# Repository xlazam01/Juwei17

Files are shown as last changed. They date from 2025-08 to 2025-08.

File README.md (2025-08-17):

<div align="center">
  <h1>Juwei17 Mount Upgrade</h1>
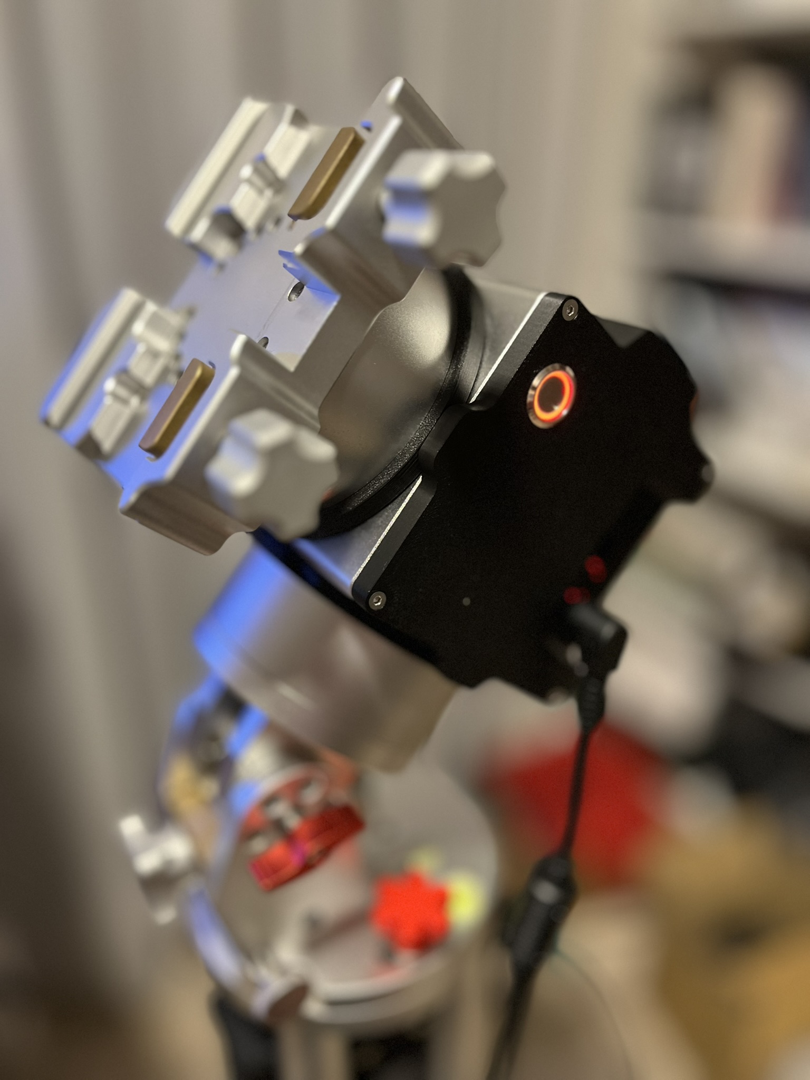
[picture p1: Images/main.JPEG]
  
</div>

## 🚀 Project Overview

This repository contains subprojects to upgrade the Juwei17 mount with enhanced hardware, software, and mechanics. The goal is to provide a modern, feature-rich, and user-friendly experience for astronomy enthusiasts.

---

## 🧑‍🔧 Skills Needed

 - Project is very DIY oriented
 - PCB is very dense and it is recommended to manufacture it via some service (JLCPCB or similar)
 - Some soldering (hall sensors, BME280, switch, connector crimping)

---

## ✨ Upgrade Features

- **Larger on/off switch**
- **Homing**
- **GPS**
- **Weather sensors**
- **Fast slewing possible**
- **Support for TMC SPI or UART modules**  
  (TMC2209, TMC2130, TMC5160, etc.)
- **USB-C connector**
- **Programming button** (no ST-Link needed)
- **Loader application** (semi-automatic programming for OnStep and SWS)

---

## 🧩 Hardware Features

- Minimized PCB size
- Support for Home and Limit switches
- OnWire interface
- GPS interface
- STM32F446 as main processor
- Power switch not needed:
  - Mount will start without switch connected
  - No high current goes through switch itself
  - When switch is closed, mount is off

---

## 💾 Software Features

- Based on OnStepX (preconfigured, just upload)
- Added STM32 RTC support
- Modified Weather:
  - Due to excessive BME self-heating
  - Temperature from DS1820
  - Humidity and pressure from BME280
- TLS fallback (STM32 → GPS)
- PlatformIO is used for OnStepX - My preferred IDE
- Arduino for SWS - due to specific version of ESP toolchain needed

---

## 🏗️ Mechanics

- CAD files
- STL files for 3D printing new covers

---

## 📦 Required Components

- New hardware - data on this github repo
- 2x TMC Drivers - you can reuse TMC2209 from your original main board
  - TMC2209 UART - [link](https://www.aliexpress.com/item/33028050145.html)
  - TMC2130 SPI - [link](https://www.aliexpress.com/item/32970150483.html)
  - TMC5160 SPI - [link](https://www.aliexpress.com/item/1005006043696147.html)
- Beitian BK-280 GPS module -  [link](https://www.aliexpress.com/item/1005009032383874.html)
- BME280 module - [link](https://www.aliexpress.com/item/1005007070789246.html)
- DS1820 - [link](https://www.aliexpress.com/item/1005009032259334.html)
- 2× 3144 hall sensors for homing functionality [link](https://www.aliexpress.com/item/1005008305500149.html)
- 16mm antivandal switch - 16mm, 12-24V, latching - [link](https://www.aliexpress.com/item/1005007144363231.html)
- Wires, connectors, hot glue, etc.
- Crimping pliers (Iwiss IWS-2820M)
- Magnetic rings:
  - Magnets 20×5×2mm [link](https://www.aliexpress.com/item/1005009668801201.html)
    ⚠️ *Warning: Large deviation in sizes experienced!*
- Screws M2×6 Voron style self-tapping screws - [link](https://www.aliexpress.com/item/1005003604942716.html)
- 4x M3x16, 4x  M3x10 countersunk
- optional 3144 hall sensor module for test [link](https://www.aliexpress.com/item/1005009110720818.html)
  - 5V power
  - It can help you to check polarity and sensitivity for you DIY magnet rings

---

## 🛠️ Building Tips

- Use hot glue to fix hall sensors and wires
- Mind the hall sensor "polarity" and magnets orientation in rings - good to check with dry run before mounting everything together

---

## 📁 Folder Description

- **CAD**: SolidEdge models (`*.par` files)
- **HW**: KiCad files (design and schematic PDF)
- **Images**: Build images
- **OnstepEspLoader**: Python app to support you through flashing process
- **OnStepX**: OnStep code (PlatformIO and VSCode)
- **SmartWebServer**: ESP8266 code (built in Arduino due to specific Espressif version)
- **STLs**: Files for 3D printing

---

## 📝 ToDo

- PEC

---

## 🖼️ Photo Gallery
<div align="center">
    Juwei17 Upgrade
</div>

<div align="center">
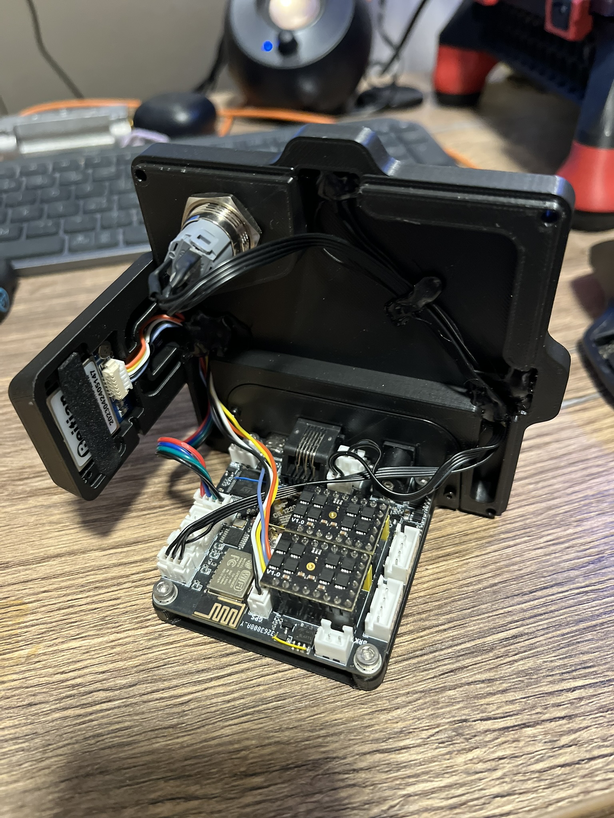
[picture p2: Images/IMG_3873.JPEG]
    
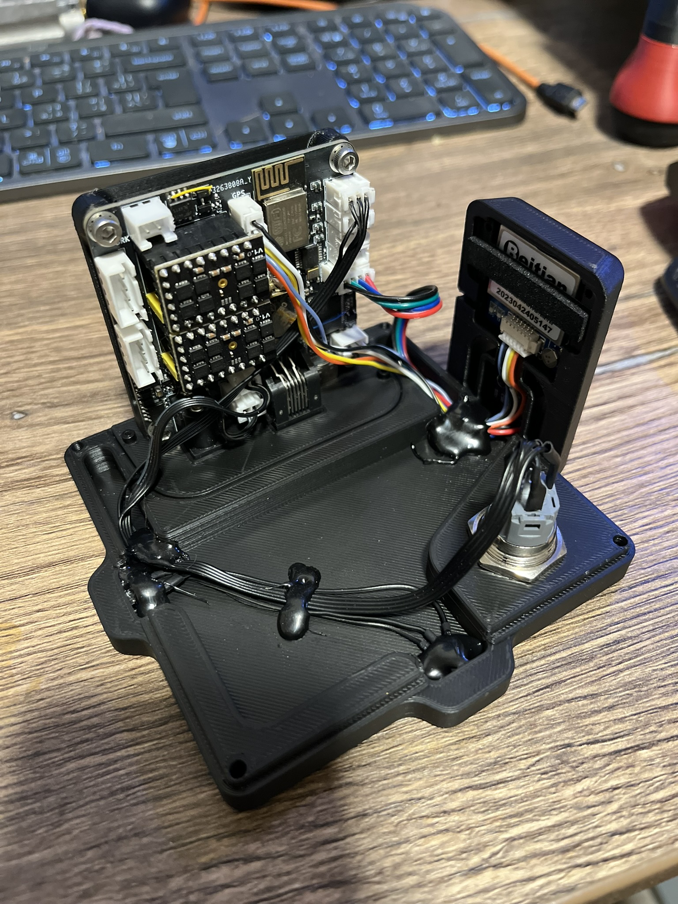
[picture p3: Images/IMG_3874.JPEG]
    
</div>
<div align="center">
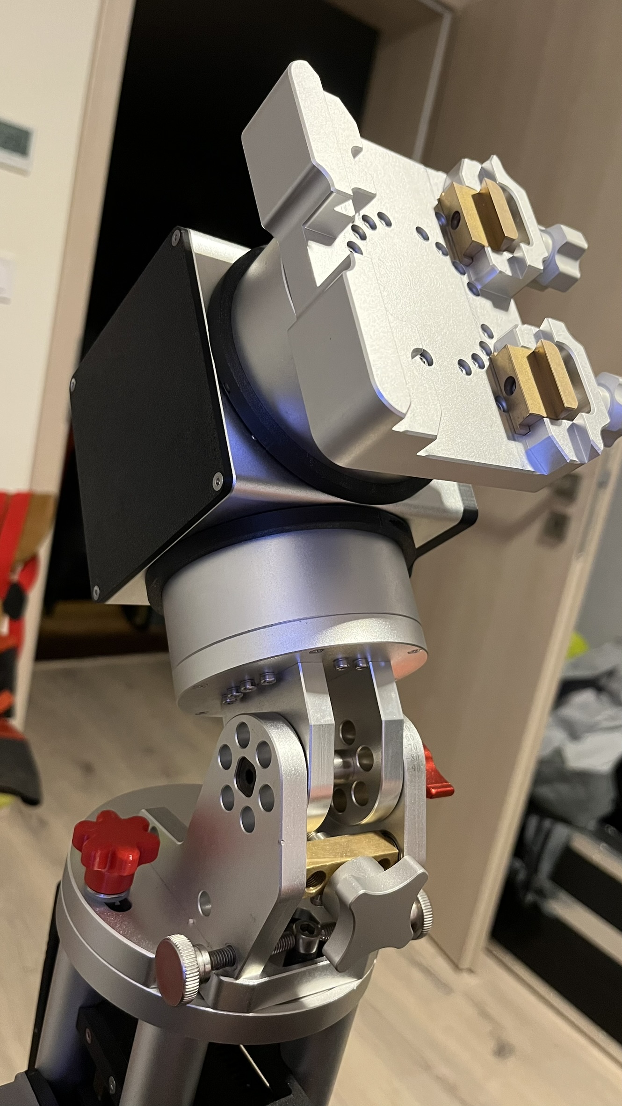
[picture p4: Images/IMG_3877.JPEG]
    
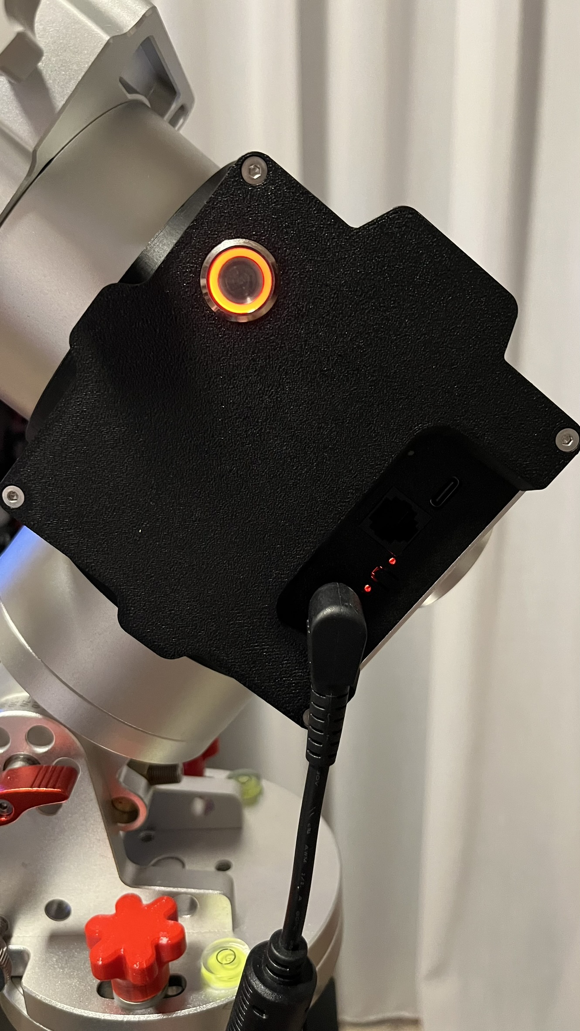
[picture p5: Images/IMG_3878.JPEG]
    
</div>
<div align="center">
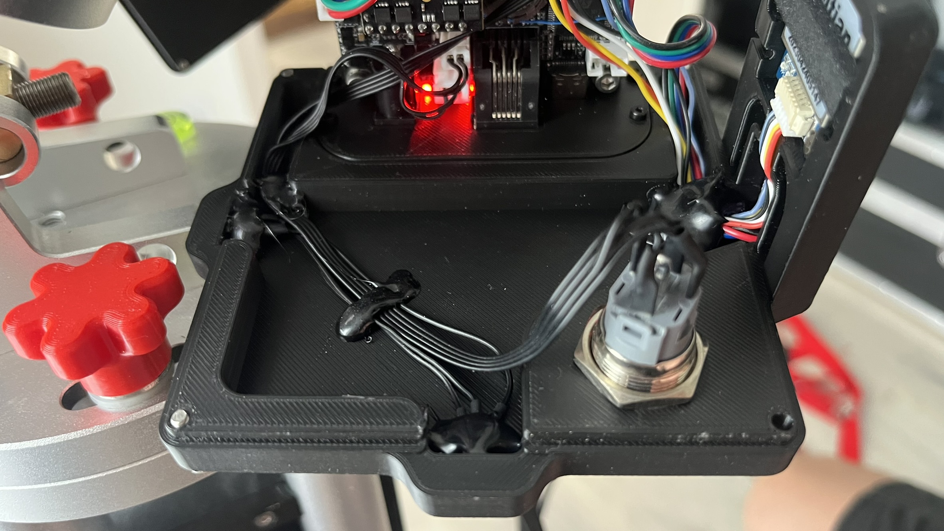
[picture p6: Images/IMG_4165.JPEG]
    
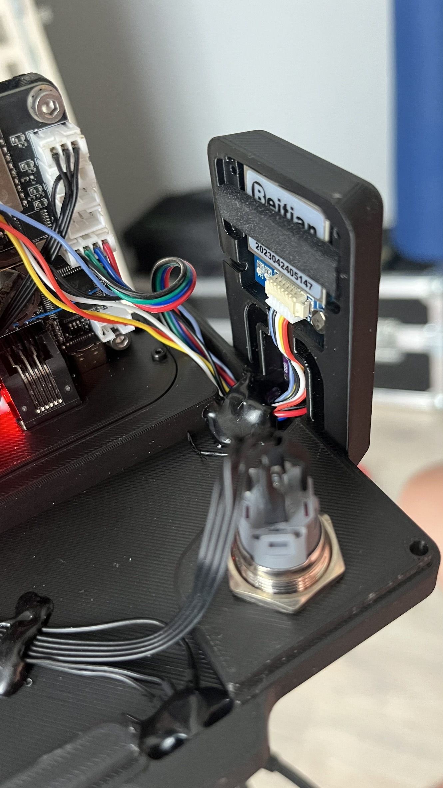
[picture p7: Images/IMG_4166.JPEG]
    
</div>
<div align="center">
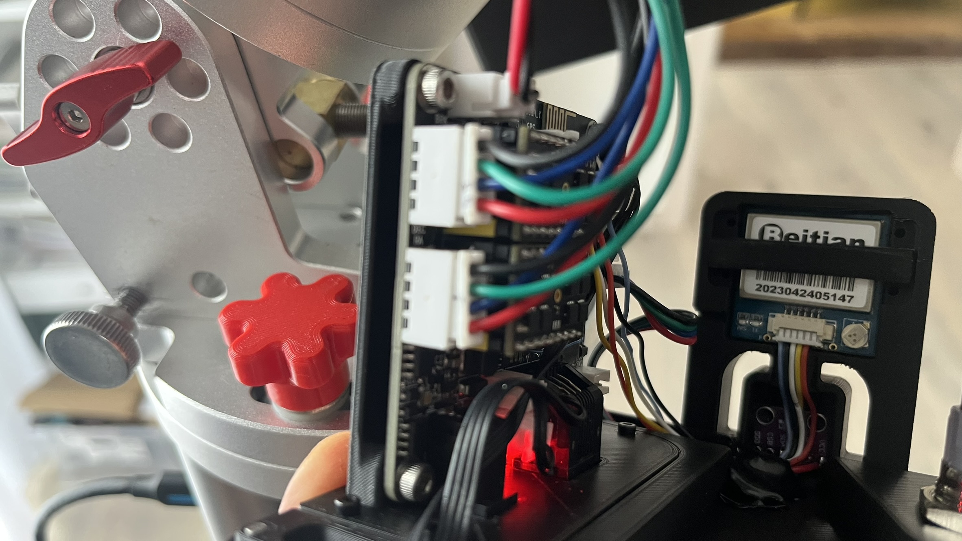
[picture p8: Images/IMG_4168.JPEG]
    
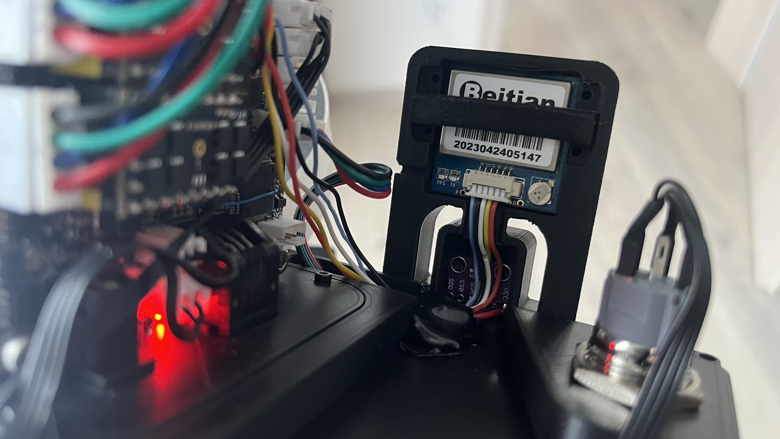
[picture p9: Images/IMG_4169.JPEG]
    
</div>
<div align="center">
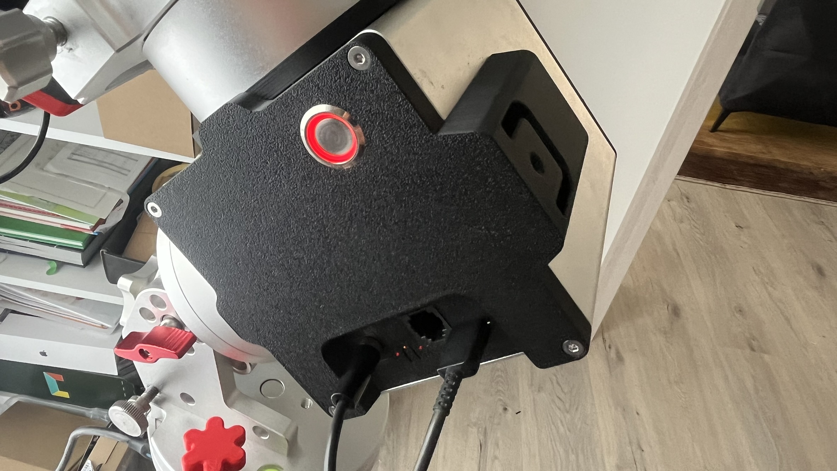
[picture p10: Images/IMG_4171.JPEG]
    
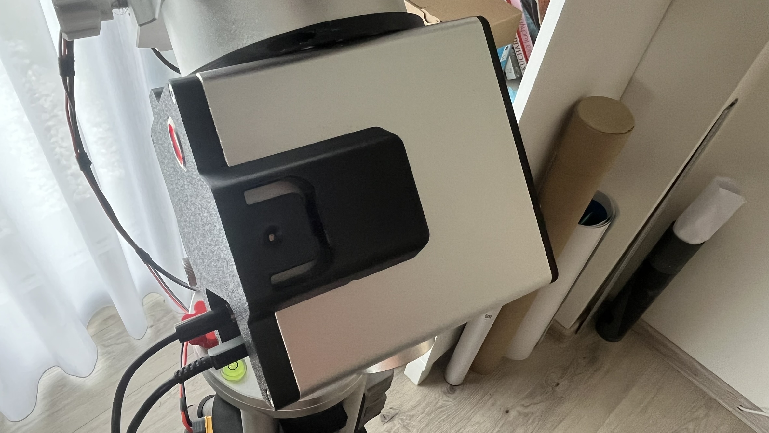
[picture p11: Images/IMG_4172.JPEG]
    
</div>
<div align="center">
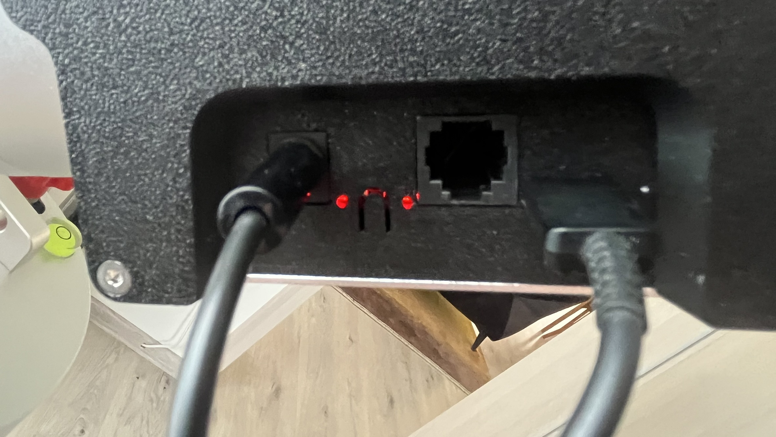
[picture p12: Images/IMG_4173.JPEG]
    
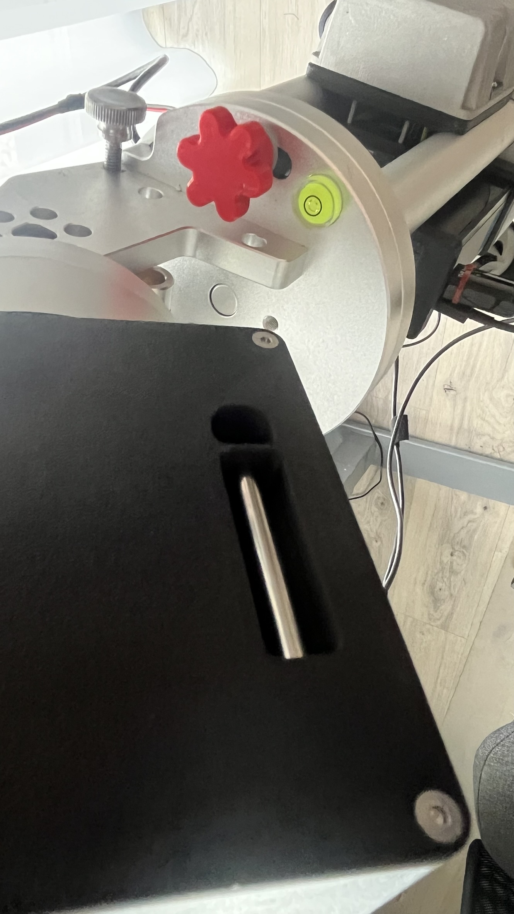
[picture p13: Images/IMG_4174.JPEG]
    
</div>

---

## 🛠️ Assembly Instructions

1. **Print the required parts.**
2. **Prepare magnets for the magnet rings:**
    - Ensure all magnets are oriented in the same direction.
    - Take care to prevent magnets from snapping together unexpectedly.
    - Test magnet polarity using a 3144 module or a bare sensor.
3. **Insert magnets into the rings.**
    - Fill roughly 90-180degrees
4. **Secure magnets with a thin layer of epoxy.**
    - 5min epoxy is ideal
5. **Assemble the front cover using small screws.**
    - Put together PCB_holder and front_panel
6. **Install hall sensors and wiring into the new cover.**
    - Insert hall sensor with right orientation (double check)
    - Fix them in place with hotglue
7. **Mount the new 16mm switch and do wiring.**
    - We use NO contact for mount ON, NC contact for mount OFF
    - Switch backlight is connected to mainboard
8. **Prepare and install wiring for the GPS and BME280 modules.**
    - Solder longer wires and cut them later to perfect length for BME280
    - For GPS just cut the wire to perfect length
    - Install modules in cavities
    - Fix GPS with GPS_holder and small screws
9. **Install the DS1820 sensor in the second cover.**
    - Pressfit the sensor in place
    - Cut wires to size
10. **Secure all wires with hot glue.**
    - Aim is to not have wires getting pinched during cover installation
11. **Trim wires to length and crimp connectors.**
12. **Plug in jumper for UART/SPI TMC**
13. **Insert TMC modules**
14. **PCB installation**
    - Reuse brass standoff - insert them into holes in front cover
    - Attach the PCB to these standoffs    
15. **Connect all components together.**
    - Install back cover
    - Plug in all connectors
    - Install front cover
    - Screw in four screws for the PCB from the bottom of the mount
16. **Assembly complete!**

---

<div align="center">
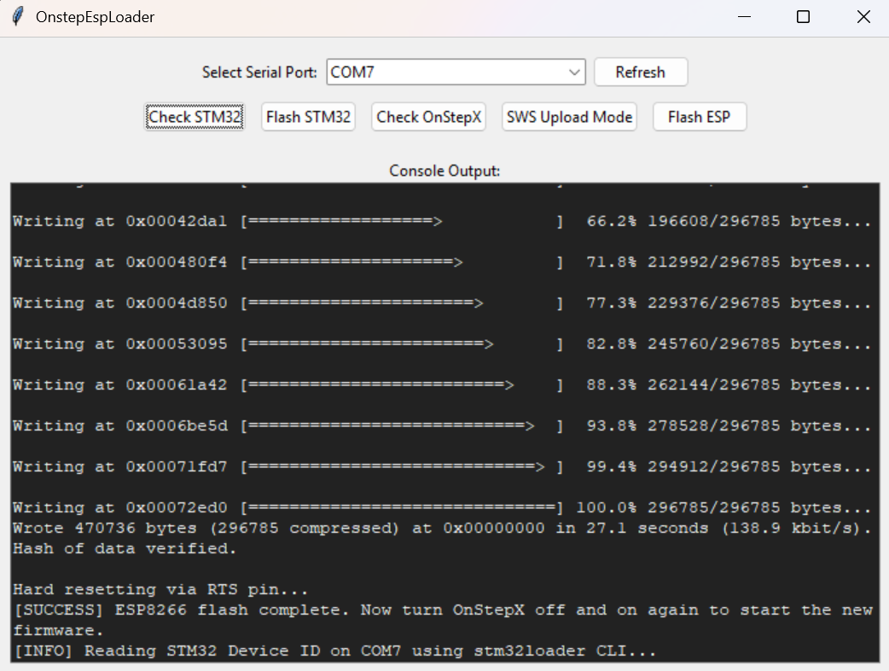
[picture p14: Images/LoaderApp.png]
    
</div>

## 💻 Firmware Upload

1. **Power off the device.**
2. **Press and hold the button** next to the power connector.
3. **Power on the device.**
4. **Observe the LEDs:**
    - OnStep status LED will be off.
    - WiFi LED will blink if firmware is present; if the ESP is empty, both LEDs will be off.
5. **Start the OnstepEspLoader Python app.**
6. **Select the correct TMC module type.**
7. **Choose homing**
8. **Click "Check STM32":**
    - The bootloader should respond.
    - If it fails, click again.
9. **Click "Upload STM32":**
    - Firmware upload will start.
10. **Wait for the OnStep status LED:**
    - It should turn on after some time.
    - The first boot may take longer as EEPROM is being formatted.
11. **Click "Check OnStep":**
    - It should respond with name and version.
12. **Switch to SWS mode:**
    - OnStep enters transparent mode and is ready to upload ESP firmware.
13. **Click "Upload ESP":**
    - Firmware for the webserver will be uploaded to the ESP.
14. **Finish:**
    - A soft reset will occur after some time, or you can power cycle the device manually.

---

## ⚙️ Default Firmware Configuration

Default firmware configuration expects:
- BME280, DS1820 - if initialization fails, there will be no weather information on webserver
- TMC2209, TMC5160 or TMC2130 - according to selected firmware during programming
- Correct polarity of HAL sensors for homing - if not fulfilled, homing will not work correctly
- Motor current is set to 1.0A for RUN and 1.3A for GOTO
- Homing sense is HIGH

---

## 🏗️ Build Your Own OnStepX

- If you use OnStepX from Howard Dutton - there will be no support for STM32 RTC (time and date will not be stored) and weather service will provide false temperatures from BME280 (self-heating)
 - This could be potentially merged into main branch (I know that STM32 RTC was not planned - there are no official boards ready for this, weather fix is open)
- For my Juwei17 board use the OnStepX from this repository
- Change configuration as needed
- For upload use Serial Bootloader - depending on your IDE (Arduino, PlatformIO) how to do it 
- There are three pads on the bottom of the PCB to connect to ST-Link - you need to solder wires or a connector with 2mm pitch
- If you want to use OnstepEspLoader just browse for your STM32 firmware binary
- Binary file pattern:

| Firmware Name | TMC Module | Homing |
|---|---|---|
| firmware_5160_wH | TMC5160 | With Homing |
| firmware_5160_woH | TMC5160 | Without Homing |
| firmware_2130_wH | TMC2130 | With Homing |
| firmware_2130_woH | TMC2130 | Without Homing |
| firmware_2209_wH | TMC2209 | With Homing |
| firmware_2209_woH | TMC2209 | Without Homing |

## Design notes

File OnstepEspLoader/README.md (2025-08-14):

# OnstepEspLoader

This is a Python application designed to upload
- firmware.bin binary file to STM32 over serial bootloader - use #serialScript.py for this
- SmartWebServer.ino.bin binary file to ESP8266

## Features
- Check presence of STM32 bootloader by get part ID
- Flash STM32 in serial bootloader
- Check presence of OnStepX
- Switch STM32 to transparent serial port by sending :hF#:ESPFLASH# to OnStep at 9600 baud to enable SWS upload mode.
- Flash ESP with SmartWebServer

## Requirements
- Python 3.7+
- pip

## Setup
1. Install dependencies:
   ```sh
   pip install stm32loader
   pip install pyserial
   ```
2. Connect your STM32/ESP32 device via USB.
3. Run the application:
   ```sh
   python main.py
   ```

## Usage
- Follow the buttons - they are self explanatory
- The script will handle the upload process.

## License
MIT

---

## 🖼️ Photo Gallery

<div align="center">
  Juwei17 Upgrade
</div>

<div align="center">
  
  
</div>
<div align="center">
  
  
</div>
<div align="center">
  
  
</div>
<div align="center">
  
  
</div>
<div align="center">
  
  
</div>
<div align="center">
  
  
</div>

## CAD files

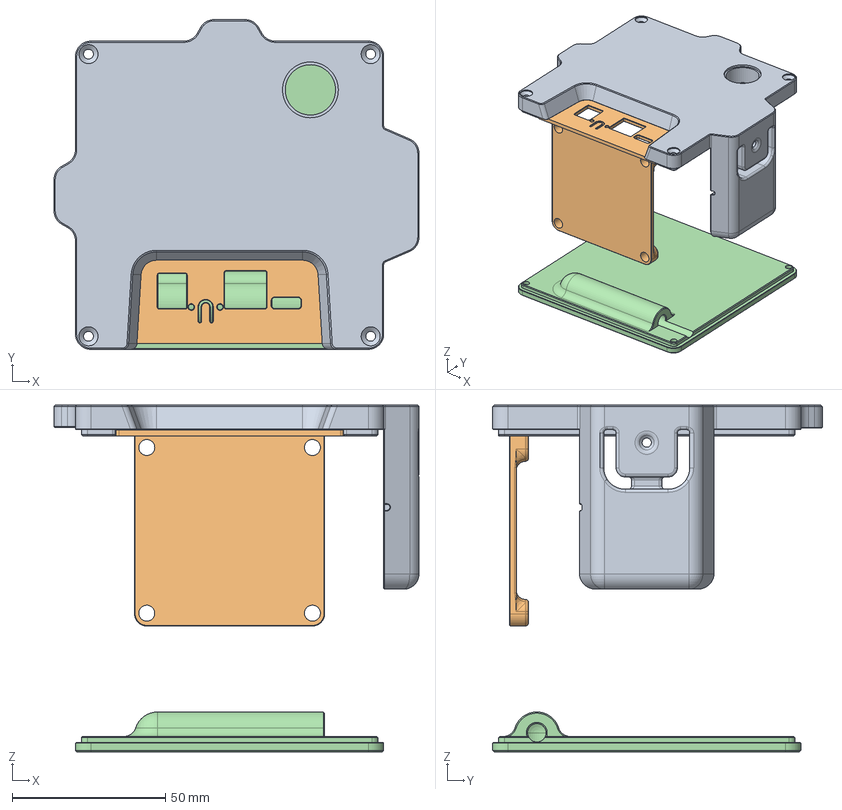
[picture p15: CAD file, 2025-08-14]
CAD/complete_assembly.stp
119.0 x 107.5 x 113.0 mm

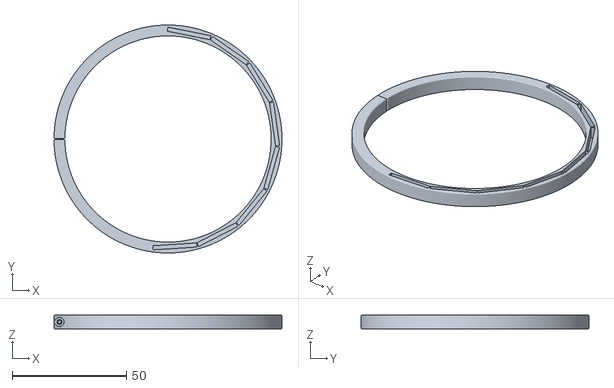
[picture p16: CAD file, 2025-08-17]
STLs/homing_ring.stl
100.0 x 100.0 x 6.00

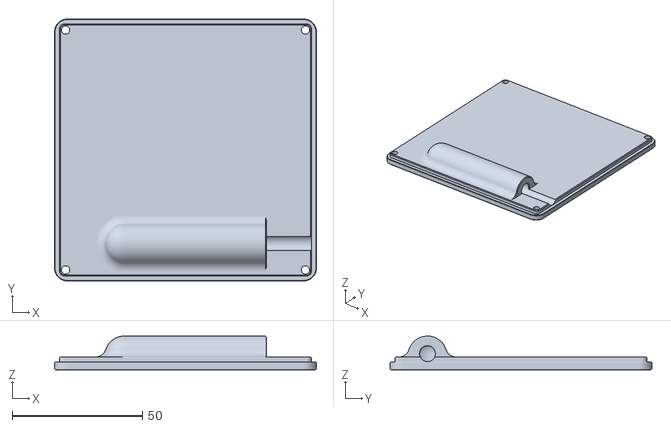
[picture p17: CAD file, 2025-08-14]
STLs/back_cover_DS1820_inside.stl
100.5 x 100.5 x 13.0

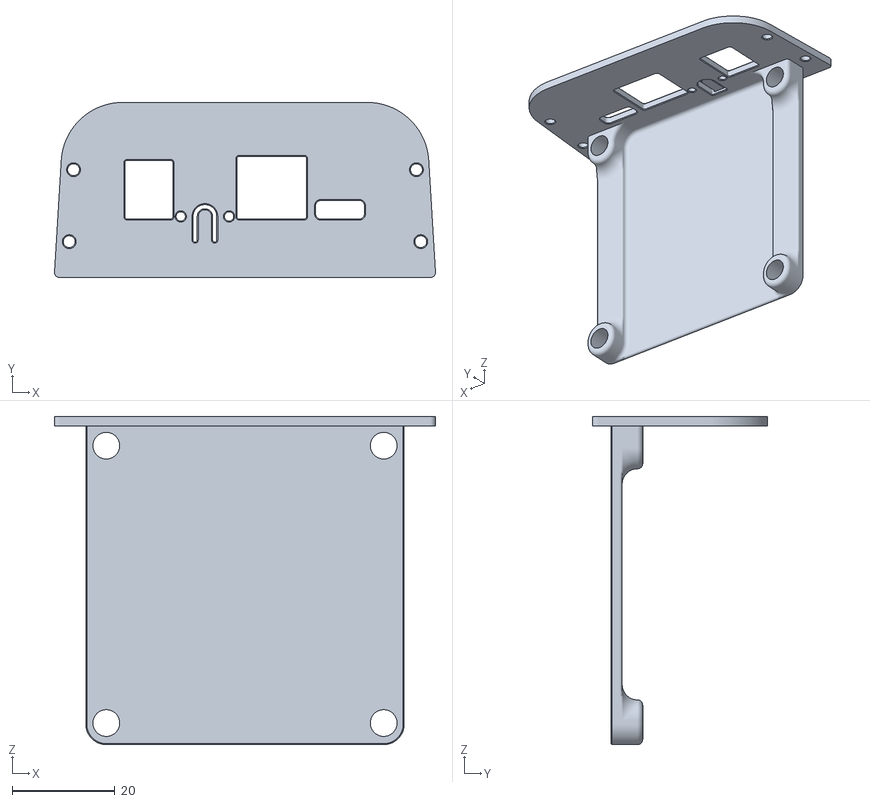
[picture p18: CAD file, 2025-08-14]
STLs/PCB_front_RJsmall.stl
74.2 x 34.1 x 63.9

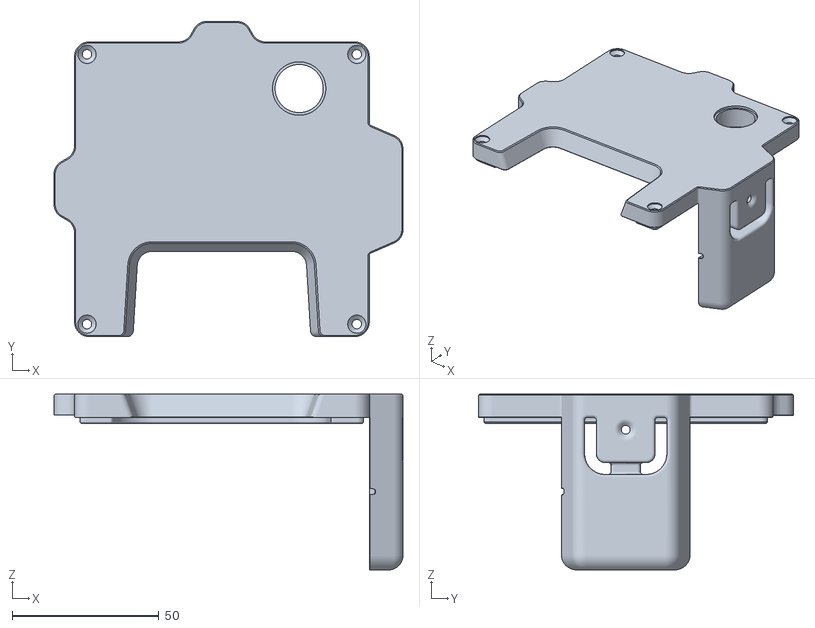
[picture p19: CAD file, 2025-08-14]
STLs/front_cover_16mm_GPS_BME.stl
119.0 x 107.5 x 60.0

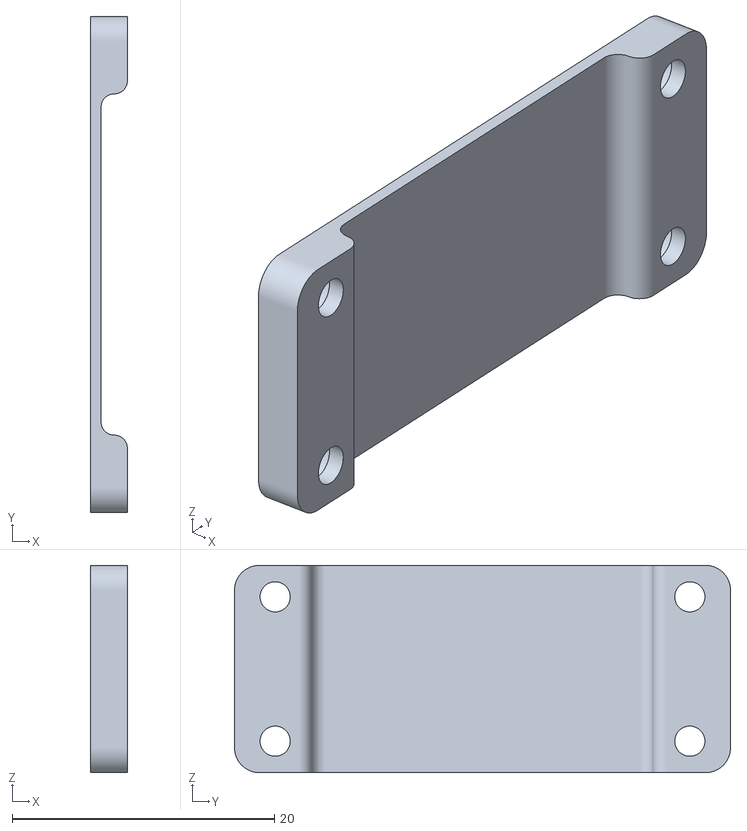
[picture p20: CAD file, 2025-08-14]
STLs/GPS_holder.stl
2.80 x 37.8 x 15.8

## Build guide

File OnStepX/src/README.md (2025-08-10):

OnStepX Telescope Controller
===========================

# What is OnStepX?
OnStepX is the advanced version of the OnStep computerized telescope controller with support for interfacing with/controlling a variety of motor drivers (and so motors) including Step/Dir, ODrive, and Servo (a combination of encoder and DC motor or Stepper motor) types.

It supports:
* Telescope Mount control (Alt/Azm and Equatorial GEM/Fork.)  Optional support for Eq mounts with Tangent Arm Declination.  Usually the Goto capability is enabled, but that's optional as well for those who just want basic mount control.
* Telescope Rotator control (including Alt/Azm de-rotation.)
* Telescope Focuser control (up to 6 focusers so it can handle collimation as well as focusing.)
* Telescope Accessory control (combination of up to 8 dew-heaters, switches, analog PWM.)

# Features
OnStepX supports a wide variety of connection options.  Several serial
"command channels" can be utilized. One of the these is normally devoted to a USB
connection and for the other(s) choose from the following:

* Bluetooth
* ESP8266 WiFi
* Arduino M0/Ethernet Shield
* Even another USB port or RS232 serial isn't very difficult to add.

In the case of running OnStepX on an ESP32 it can provide its own Bluetooth or WiFi IP command channels without additional hardware by simply activating the feature in OnStepX.

Other software in the OnStep ecosystem include:

* an [ASCOM](http://ascom-standards.org/) driver (with IP and Serial support),
* an Android App useable over WiFi or Bluetooth equipped Phones/Tablets,
* a "built-in" website (on the Ethernet and/or WiFi device),
* a full planetarium program that controls all features ([Sky Planetarium](http://stellarjourney.com/index.php?r=site/software_sky)).

OnStep is compatible with the LX200 protocol. This means it can be controlled
from other planetarium software, like: Sky Safari, CdC (even without ASCOM),
Stellarium, etc.

There are also [INDI](http://www.indilib.org/about.html) drivers so it can be used from Linux, with CdC or KStars.

# Documentation
Detailed documentation, including the full set of features, detailed designs for
PCBs, instructions on how to build a controller, how to configure the firmware
for your particular mount, can all be found the [OnStep Group Wiki](https://groups.io/g/onstep/wiki/home).

# Change Log
All the changes are tracking in git, and a detailed list can be accessed using the
following git command:
 
git log --date=short --pretty=format:"%h %ad %<(20)%an %<(150,trunc)%s"

# Support
Questions and discussion should be on the mailing list (also accessible via the
web) at the [OnStep Group](https://groups.io/g/onstep/).

# License
OnStep is open source free software, licensed under the GPL.

See [LICENSE.txt](./LICENSE.txt) file.

# Author
[Howard Dutton](http://www.stellarjourney.com)

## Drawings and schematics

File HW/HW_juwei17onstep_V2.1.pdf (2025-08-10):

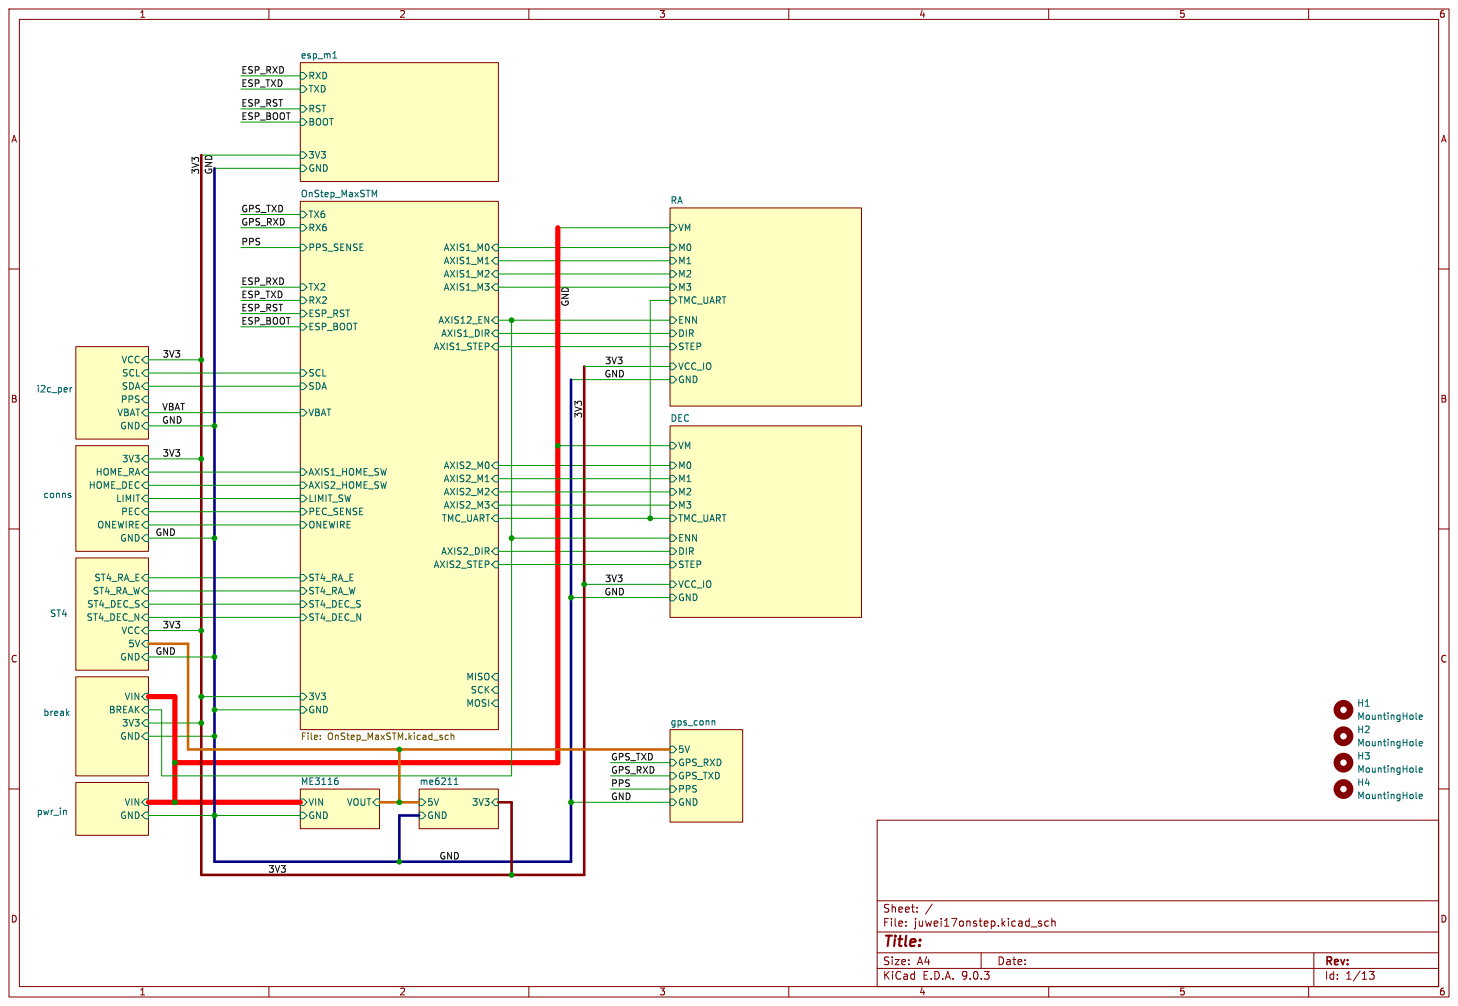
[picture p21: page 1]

Id: 1/13 Title: File: juwei17onstep.kicad_sch Sheet: /

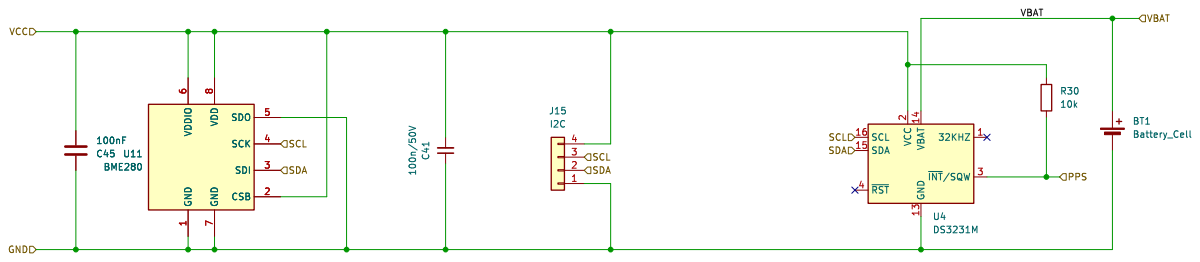
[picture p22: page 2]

7 SDO 5 SCK 4 SDI 3 CSB 2 U11 BME280

7 SDO 5 SCK 4 SDI 3 CSB 2

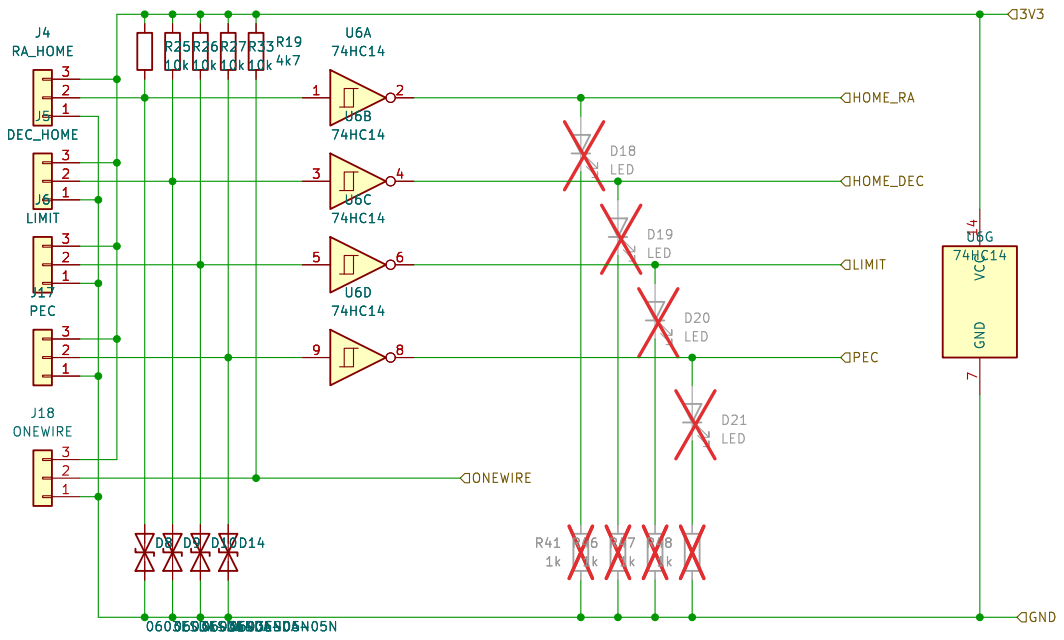
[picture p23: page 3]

Id: 11/13 Title: File: conns.kicad_sch Sheet: /conns/

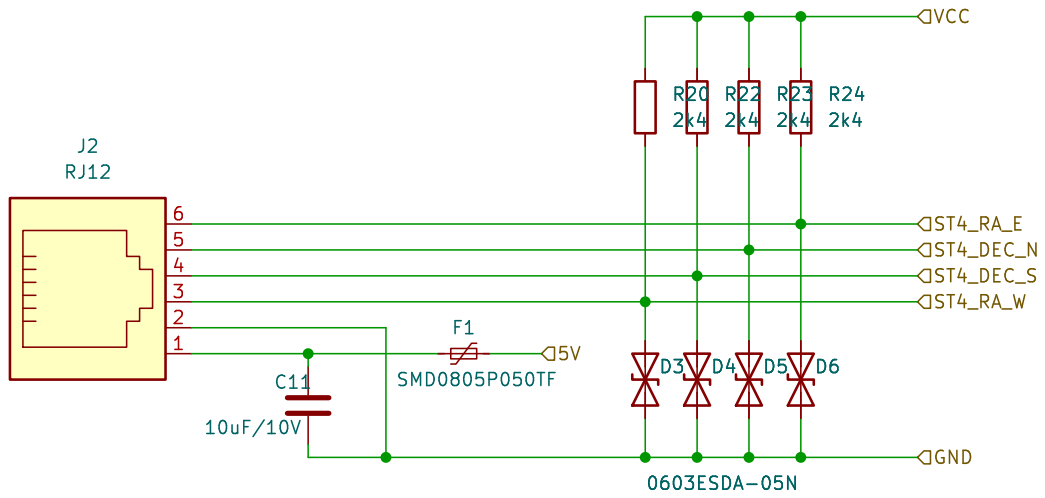
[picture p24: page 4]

Id: 7/13 Title: File: ST4.kicad_sch Sheet: /ST4/

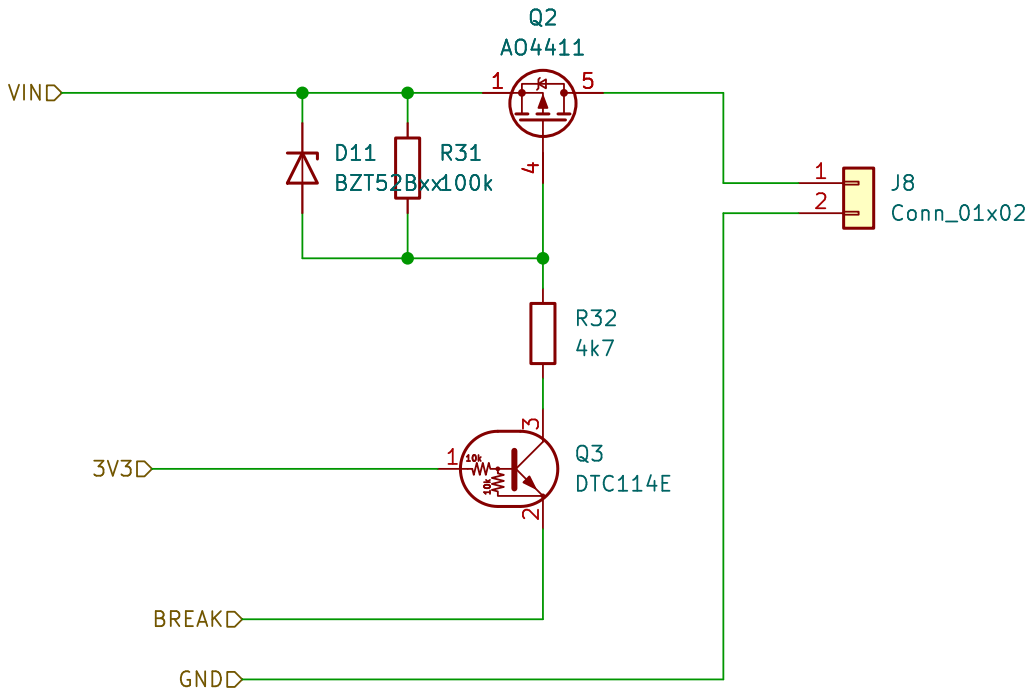
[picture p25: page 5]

Id: 14/13 Title: File: break.kicad_sch Sheet: /break/ D11 BZT52Bxx

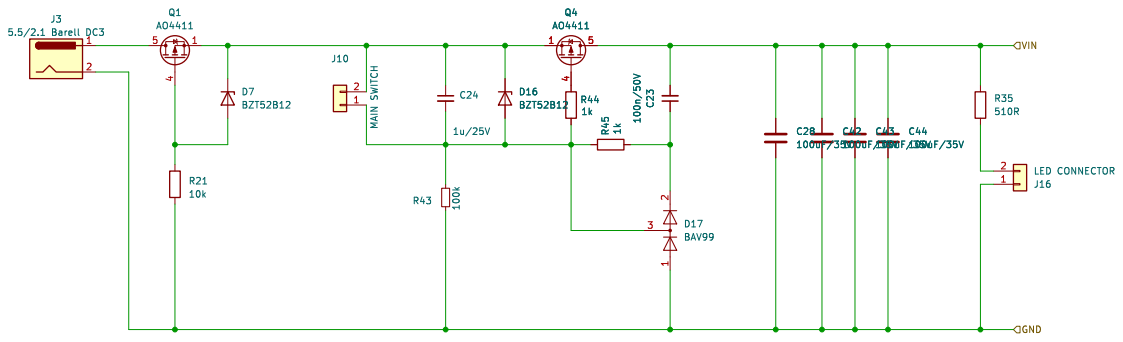
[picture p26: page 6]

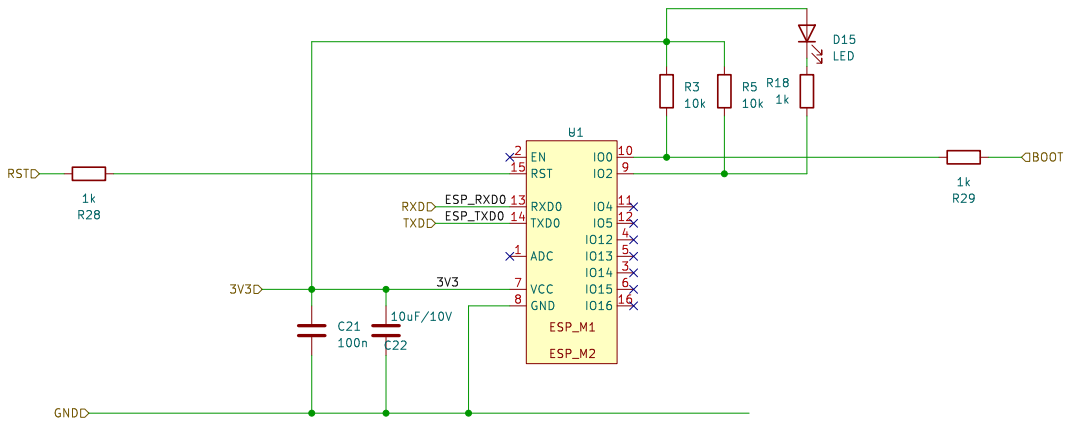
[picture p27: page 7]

Id: 6/13 Title: File: esp_m1.kicad_sch Sheet: /esp_m1/

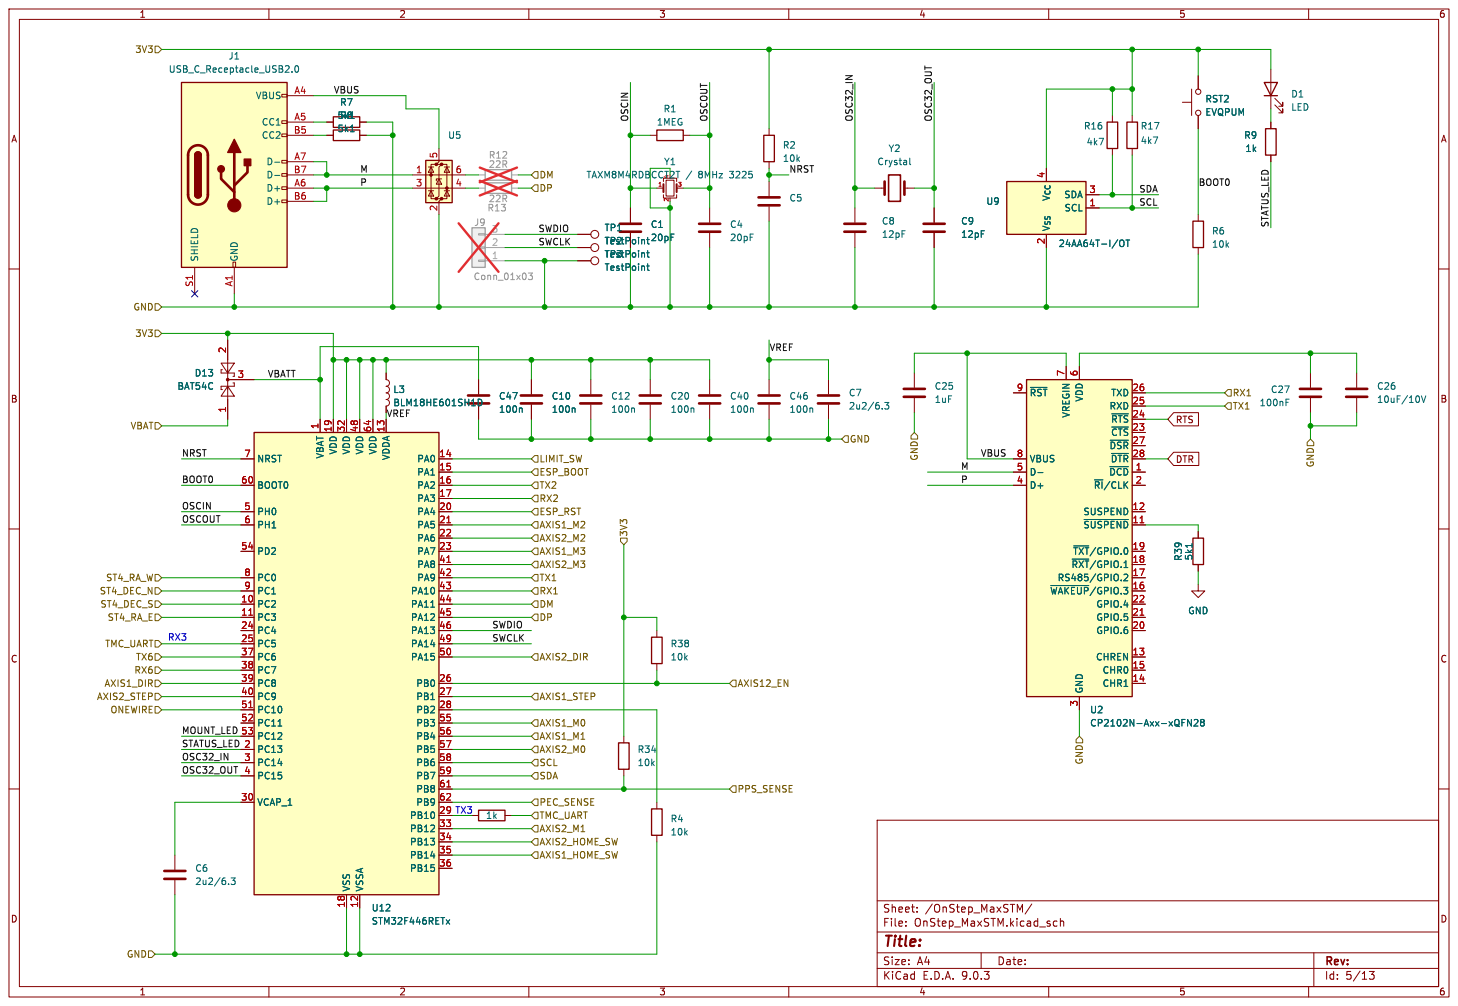
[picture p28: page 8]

3 TXD 26 RXD 25 ~{RTS} 24 ~{CTS} 23 ~{DSR} 27 ~{DTR} 28 ~{DCD}1 ~{RI}/CLK2 SUSPEND 12 ~{SUSPEND}11 ~{TXT}/GPIO.019 ~{RXT}/GPIO.118 RS485/GPIO.2 17 ~{WAKEUP}/GPIO.316 GPIO.4 22 GPIO.5 21 GPIO.6 20 CHREN 13 CHR0 15 CHR1 14 C10
DPRX2 ESP_BOOT
TX2 AXIS2_M2 AXIS1_M2 ESP_RST
AXIS1_STEP RX1 DM

3 TXD 26 RXD 25 ~{RTS} 24 ~{CTS} 23 ~{DSR} 27 ~{DTR} 28 ~{DCD}1 ~{RI}/CLK2 SUSPEND 12 ~{SUSPEND}11 ~{TXT}/GPIO.019 ~{RXT}/GPIO.118 RS485/GPIO.2 17 ~{WAKEUP}/GPIO.316 GPIO.4 22 GPIO.5 21 GPIO.6 20 CHREN 13 CHR0 15 CHR1 14 U2 CP2102N-Axx-xQFN28

1 VDD 19 VDD 32 VSS 18 VDD 48 VSSA 12 VDD 64 VDDA 13 PA0 14 PA1 15 PA2 16 PA3 17 PA4 20 PA5 21 PA6 22 PA7 23 PA8 41 PA9 42 PA10 43 PA11 44 PA12 45 PA13 46 PA14 49 PA15 50 PB0 26 PB1 27 PB2 28 PB3 55 PB4 56 PB5 57 PB6 58 PB7 59 PB8 61 PB9 62 PB10 29 PB12 33 PB13 34 PB14 35 PB15 36 U12 STM32F446RETx

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

Id: 5/13 Title: File: OnStep_MaxSTM.kicad_sch Sheet: /OnStep_MaxSTM/

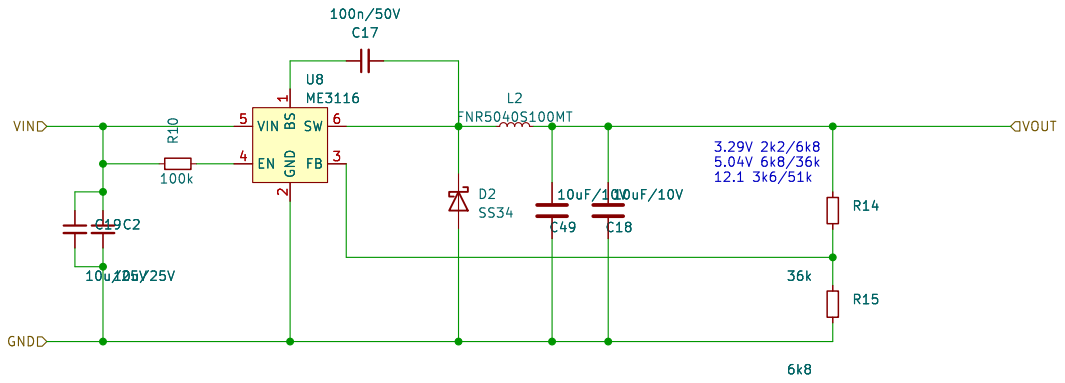
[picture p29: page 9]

Id: 8/13 Title: File: ME3116.kicad_sch Sheet: /ME3116/

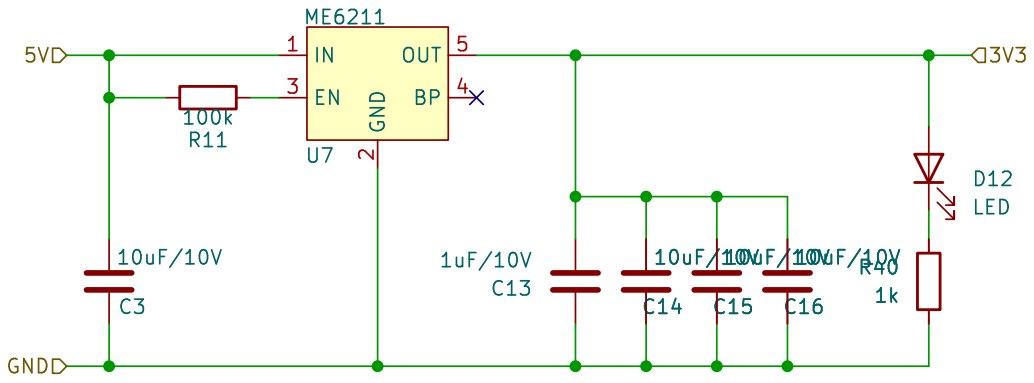
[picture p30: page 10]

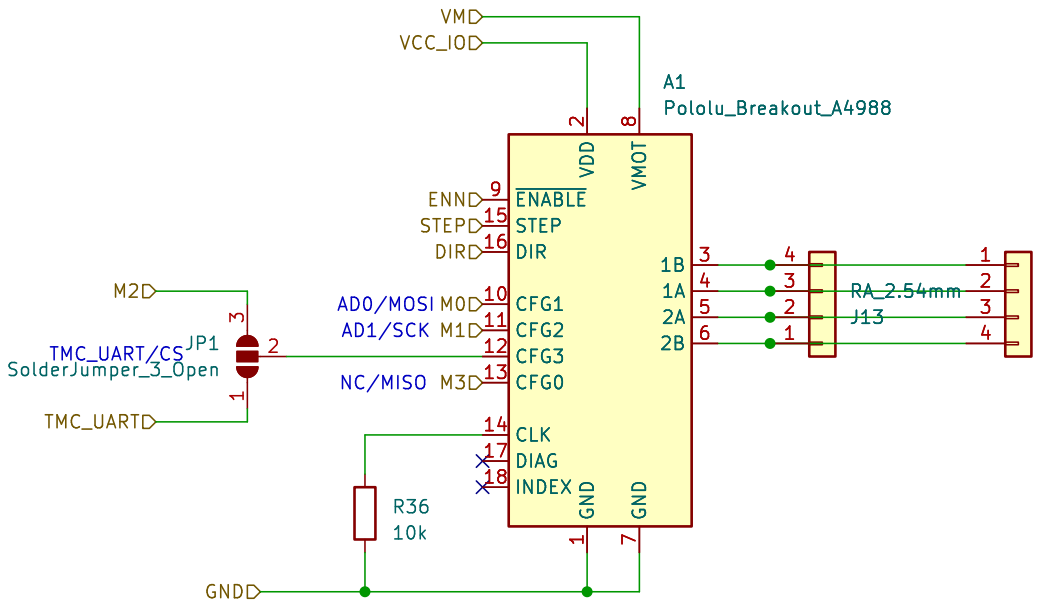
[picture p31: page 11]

Id: 2/13 Title: File: tmc2209.kicad_sch Sheet: /RA/

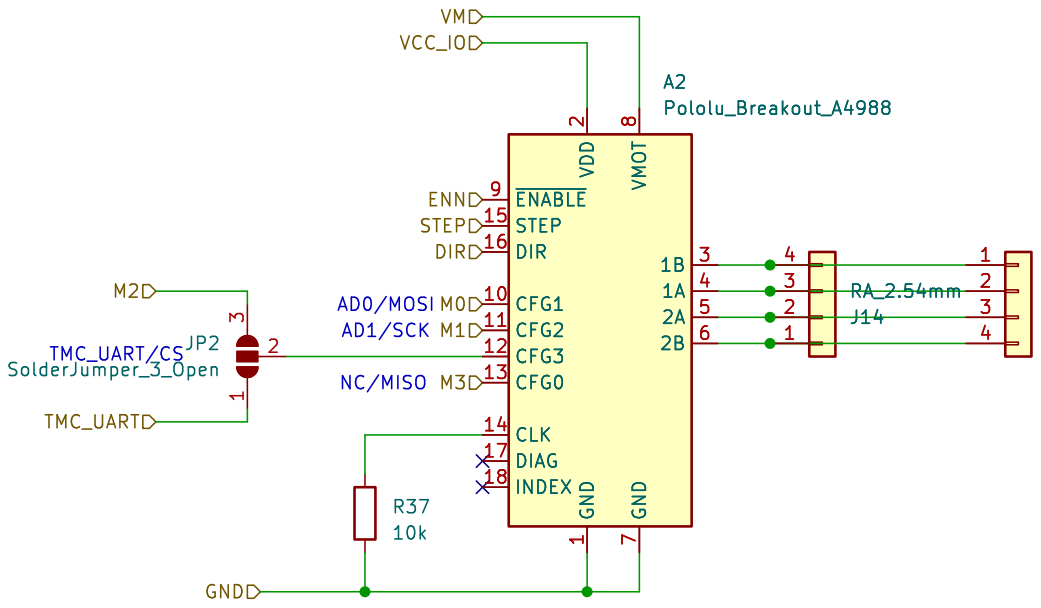
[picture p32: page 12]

Id: 3/13 Title: File: tmc2209.kicad_sch Sheet: /DEC/


Id: 10/13 Title: File: gps_conn.kicad_sch Sheet: /gps_conn/

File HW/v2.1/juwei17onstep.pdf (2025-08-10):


Id: 1/13 Title: File: juwei17onstep.kicad_sch Sheet: /


7 SDO 5 SCK 4 SDI 3 CSB 2 U11 BME280

7 SDO 5 SCK 4 SDI 3 CSB 2


Id: 11/13 Title: File: conns.kicad_sch Sheet: /conns/


2 | D3

Id: 7/13 Title: File: ST4.kicad_sch Sheet: /ST4/


Id: 14/13 Title: File: break.kicad_sch Sheet: /break/ D11 BZT52Bxx



Id: 6/13 Title: File: esp_m1.kicad_sch Sheet: /esp_m1/


3 TXD 26 RXD 25 ~{RTS} 24 ~{CTS} 23 ~{DSR} 27 ~{DTR} 28 ~{DCD}1 ~{RI}/CLK2 SUSPEND 12 ~{SUSPEND}11 ~{TXT}/GPIO.019 ~{RXT}/GPIO.118 RS485/GPIO.2 17 ~{WAKEUP}/GPIO.316 GPIO.4 22 GPIO.5 21 GPIO.6 20 CHREN 13 CHR0 15 CHR1 14 C10
DPRX2 ESP_BOOT
TX2 AXIS2_M2 AXIS1_M2 ESP_RST
AXIS1_STEP RX1 DM

3 TXD 26 RXD 25 ~{RTS} 24 ~{CTS} 23 ~{DSR} 27 ~{DTR} 28 ~{DCD}1 ~{RI}/CLK2 SUSPEND 12 ~{SUSPEND}11 ~{TXT}/GPIO.019 ~{RXT}/GPIO.118 RS485/GPIO.2 17 ~{WAKEUP}/GPIO.316 GPIO.4 22 GPIO.5 21 GPIO.6 20 CHREN 13 CHR0 15 CHR1 14 U2 CP2102N-Axx-xQFN28

1 VDD 19 VDD 32 VSS 18 VDD 48 VSSA 12 VDD 64 VDDA 13 PA0 14 PA1 15 PA2 16 PA3 17 PA4 20 PA5 21 PA6 22 PA7 23 PA8 41 PA9 42 PA10 43 PA11 44 PA12 45 PA13 46 PA14 49 PA15 50 PB0 26 PB1 27 PB2 28 PB3 55 PB4 56 PB5 57 PB6 58 PB7 59 PB8 61 PB9 62 PB10 29 PB12 33 PB13 34 PB14 35 PB15 36 U12 STM32F446RETx

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

Id: 5/13 Title: File: OnStep_MaxSTM.kicad_sch Sheet: /OnStep_MaxSTM/


Id: 8/13 Title: File: ME3116.kicad_sch Sheet: /ME3116/



Id: 2/13 Title: File: tmc2209.kicad_sch Sheet: /RA/


Id: 3/13 Title: File: tmc2209.kicad_sch Sheet: /DEC/


Id: 10/13 Title: File: gps_conn.kicad_sch Sheet: /gps_conn/

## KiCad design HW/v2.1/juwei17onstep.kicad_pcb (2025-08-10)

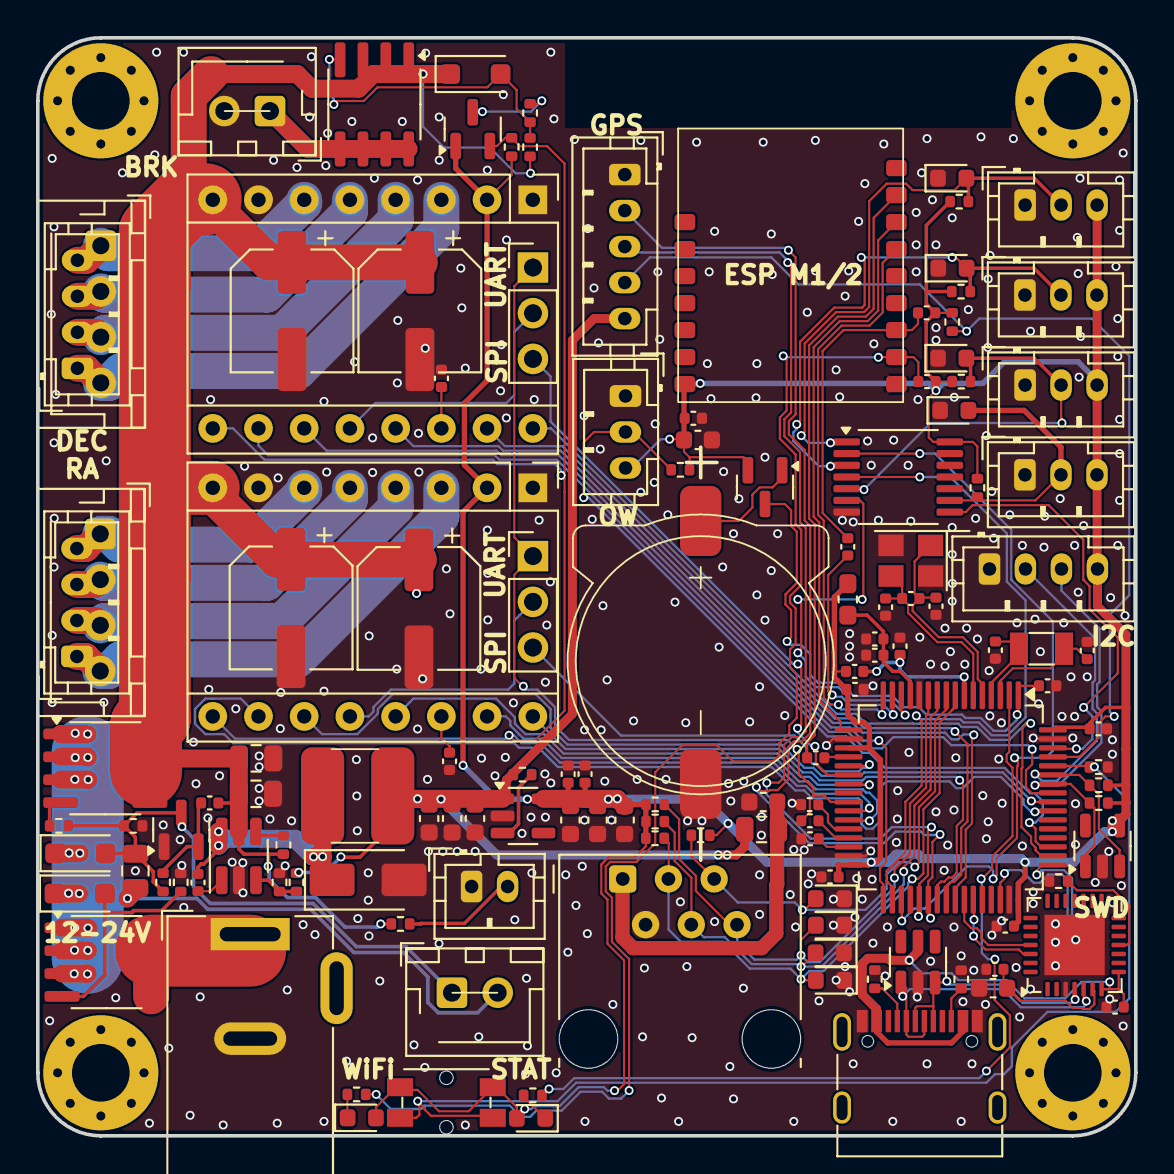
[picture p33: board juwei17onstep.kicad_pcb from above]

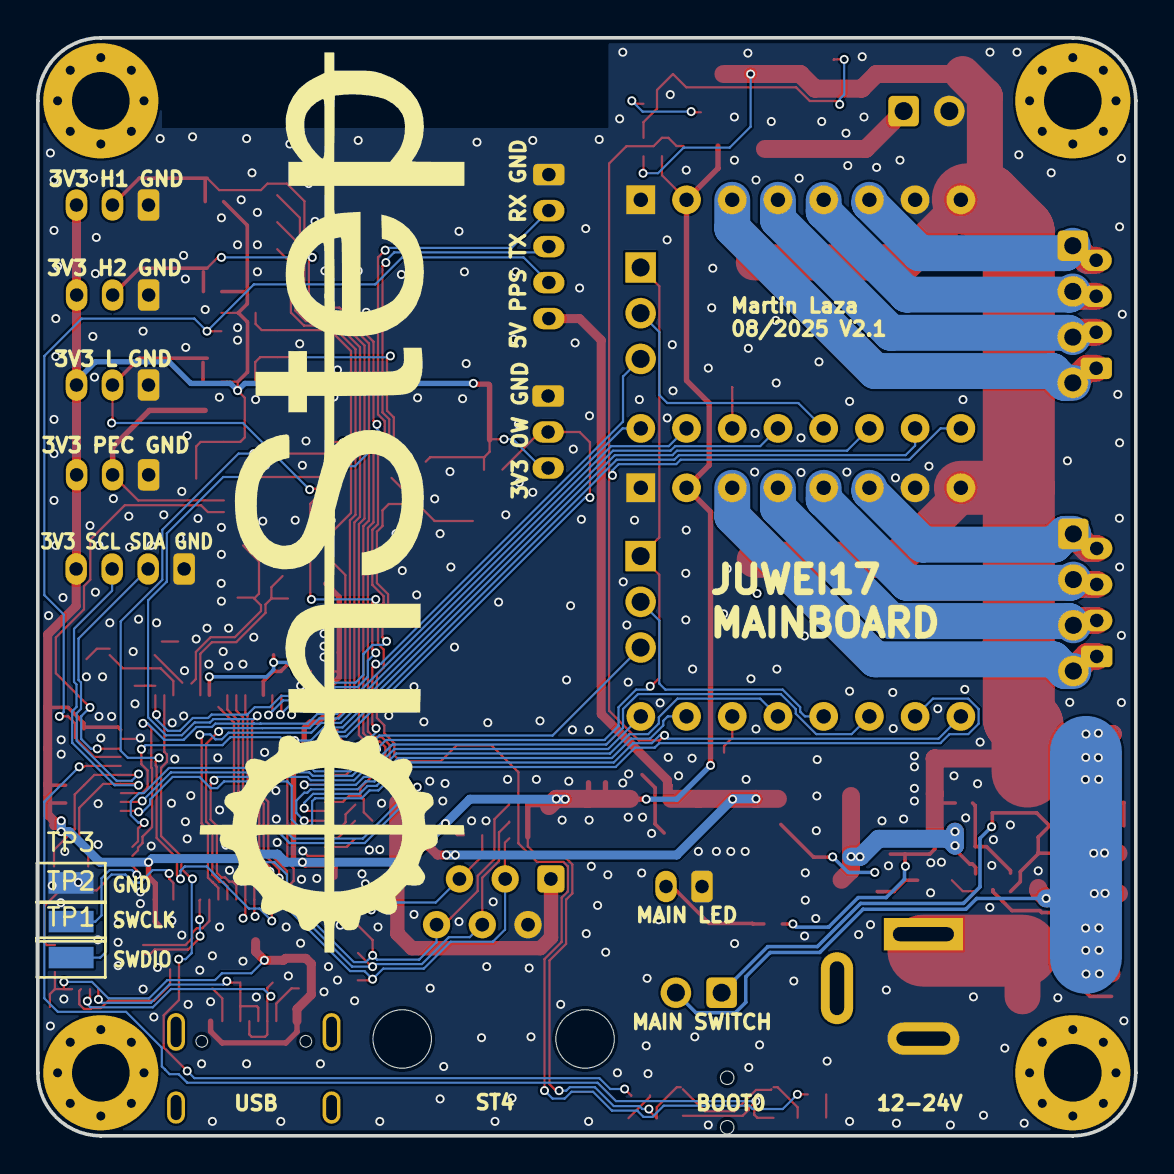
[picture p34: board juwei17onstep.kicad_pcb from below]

Board: 2 copper layers, 61.0 x 61.0 mm, 139 parts (3 on the bottom side), 97 nets.

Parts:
A1, A2: Pololu_Breakout_A4988; StepStick
BT1: Battery_Cell; CR1220_holder
C1, C4: 20pF; C_0402_1005Metric
C2, C19: 10u/25V; C_0805_2012Metric
C3, C11, C14, C15, C16, C18, C22, C26, C49: 10uF/10V; C_0603_1608Metric
C5, C13: 1uF/10V; C_0402_1005Metric
C6, C7: 2u2/6.3; C_0402_1005Metric
C8, C9: 12pF; C_0402_1005Metric
C10, C12, C20, C21, C40, C46, C47: 100n; C_0402_1005Metric
C17, C23, C41: 100n/50V; C_0402_1005Metric
C24: 1u/25V; C_0805_2012Metric
C25: 1uF; C_0402_1005Metric
C27: 100nF; C_0402_1005Metric
C28, C42, C43, C44: 100uF/35V; CP_Elec_6.3x7.7
D1, D15: LED; LED_0603_1608Metric
D2: SS34; D_SMA
D3, D4, D5, D6, D8, D9, D10, D14: 0603ESDA-05N; D_0603_1608Metric
D7, D16: BZT52B12; D_SOD-123F
D11: BZT52Bxx; D_SOD-123F
D13: BAT54C; SOT-23
D17: BAV99; SOT-23
F1: SMD0805P050TF; Fuse_0805_2012Metric
H1, H2, H3, H4: MountingHole; MountingHole_3.2mm_M3_Pad_Via
J1: USB_C_Receptacle_USB2.0; USB_C_Receptacle_G-Switch_GT-USB-7010ASV
J2: RJ12; RJ12_Amphenol_54601-x06_Horizontal
J3: 5.5/2.1 Barell DC3; BarrelJack_Wuerth_6941xx301002
J4: RA_HOME; JST_PH_B3B-PH-K_1x03_P2.00mm_Vertical
J5: DEC_HOME; JST_PH_B3B-PH-K_1x03_P2.00mm_Vertical
J6: LIMIT; JST_PH_B3B-PH-K_1x03_P2.00mm_Vertical
J7: GPS; JST_PH_B5B-PH-K_1x05_P2.00mm_Vertical
J8: Conn_01x02; JST_1x02_P2.54
J10: MAIN SWITCH; JST_1x02_P2.54
J11, J12: RA_2mm; JST_PH_B4B-PH-K_1x04_P2.00mm_Vertical
J13, J14: RA_2.54mm; JST_1x04_P2.54
J15: I2C; JST_PH_B4B-PH-K_1x04_P2.00mm_Vertical
J16: LED CONNECTOR; JST_PH_B2B-PH-K_1x02_P2.00mm_Vertical
J17: PEC; JST_PH_B3B-PH-K_1x03_P2.00mm_Vertical
J18: ONEWIRE; JST_PH_B3B-PH-K_1x03_P2.00mm_Vertical
JP1, JP2: SolderJumper_3_Open; PinHeader_1x03_P2.54mm_Vertical
L2: FNR5040S100MT; L_5.5x5.1mm
L3: BLM18HE601SH1D; L_0603_1608Metric_Pad1.05x0.95mm_HandSolder
Q1, Q2, Q4: AO4411; SOIC-8_3.9x4.9mm_P1.27mm
Q3: DTC114E; SOT-23
R1: 1MEG; C_0402_1005Metric
R2, R3, R4, R5, R36, R37: 10k; C_0402_1005Metric
R6, R21, R25, R26, R27, R33, R34, R38: 10k; R_0402_1005Metric
R7, R8, R39: 5k1; R_0402_1005Metric
R9, R18, R44, R45: 1k; R_0402_1005Metric
R10, R11, R31, R43: 100k; R_0402_1005Metric
R14: 36k; R_0402_1005Metric
R15: 6k8; R_0402_1005Metric
R16, R17, R19, R32: 4k7; R_0402_1005Metric
R20, R22, R23, R24: 2k4; R_0402_1005Metric
R28, R29, R42: 1k; C_0402_1005Metric
R35: 510R; R_0402_1005Metric
RST2: EVQPUM; Panasonic_EVQPUM_EVQPUD
TP1, TP2, TP3: TestPoint; TestPoint_Keystone_5015_Micro-Minature
U1: ESP_M2
U2: CP2102N-Axx-xQFN28; QFN-28-1EP_5x5mm_P0.5mm_EP3.35x3.35mm
U5: USBLC6-2SC6; SOT-23-6
U6: 74HC14; TSSOP-14_4.4x5mm_P0.65mm
U7: ME6211; SOT-23-5
U8: ME3116; SOT-23-6_Handsoldering
U9: 24AA64T-I/OT; SOT-23-5
U12: STM32F446RETx; LQFP-64_10x10mm_P0.5mm
Y1: TAXM8M4RDBCCT2T / 8MHz 3225; Crystal_SMD_3225-4Pin_3.2x2.5mm
Y2: Crystal; Crystal_SMD_3215-2Pin_3.2x1.5mm

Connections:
/3V3: A1.2 (VDD), A2.2 (VDD), C10.1, C12.1, C13.2, C14.2, C15.2, C16.2, C20.1, C21.1, C22.2, C40.1, C41.2, D1.2 (A), D13.2, D15.2 (A), J4.3, J5.3, J6.3, J15.4, J17.3, J18.3, L3.1, Q3.1 (B), R2.2, R3.2, R5.2, R16.2, R17.2, R19.2, R20.2, R22.2, R23.2, R24.2, R25.2, R26.2, R27.2, R33.2, R34.2, R38.2, RST2.2, U1.7 (VCC), U6.14 (VCC), U7.5 (OUT), U9.4 (V_{CC}), U12.19 (VDD), U12.32 (VDD), U12.48 (VDD), U12.64 (VDD)
/DEC/DIR: A2.16 (DIR), U12.50 (PA15)
/DEC/ENN: A1.9 (~ENABLE), A2.9 (~ENABLE), Q3.2 (E), R38.1, U12.26 (PB0)
/DEC/M0: A2.10 (CFG1), U12.57 (PB5)
/DEC/M1: A2.11 (CFG2), U12.33 (PB12)
/DEC/M2: JP2.3 (B), U12.22 (PA6)
/DEC/M3: A2.13 (CFG0), U12.41 (PA8)
/DEC/STEP: A2.15 (STEP), U12.40 (PC9)
/DEC/TMC_UART: JP1.1 (A), JP2.1 (A), R42.1, U12.25 (PC5)
/DEC/VM: A1.8 (VMOT), A2.8 (VMOT), C2.1, C19.1, C23.2, C28.1, C42.1, C43.1, C44.1, D11.1 (K), Q2.1 (S), Q2.2 (S), Q2.3 (S), Q4.5 (D), Q4.6 (D), Q4.7 (D), Q4.8 (D), R10.2, R31.2, R35.2, U8.5 (VIN)
/ESP_BOOT: R29.2, U12.15 (PA1)
/ESP_RST: R28.1, U12.20 (PA4)
/ESP_RXD: U1.13 (RXD0), U12.16 (PA2)
/ESP_TXD: U1.14 (TXD0), U12.17 (PA3)
/GPS_RXD: J7.2, U12.38 (PC7)
/GPS_TXD: J7.3, U12.37 (PC6)
/ME3116/VOUT: C3.2, C18.2, C49.2, F1.2, J7.5, L2.2, R11.2, R14.2, U7.1 (IN)
/OnStep_MaxSTM/AXIS1_DIR: A1.16 (DIR), U12.39 (PC8)
/OnStep_MaxSTM/AXIS1_HOME_SW: U6.2, U12.35 (PB14)
/OnStep_MaxSTM/AXIS1_M0: A1.10 (CFG1), U12.55 (PB3)
/OnStep_MaxSTM/AXIS1_M1: A1.11 (CFG2), U12.56 (PB4)
/OnStep_MaxSTM/AXIS1_M2: JP1.3 (B), U12.21 (PA5)
/OnStep_MaxSTM/AXIS1_M3: A1.13 (CFG0), U12.23 (PA7)
/OnStep_MaxSTM/AXIS1_STEP: A1.15 (STEP), U12.27 (PB1)
/OnStep_MaxSTM/AXIS2_HOME_SW: U6.4, U12.34 (PB13)
/OnStep_MaxSTM/BOOT0: R6.2, RST2.1, U12.60 (BOOT0)
/OnStep_MaxSTM/LIMIT_SW: U6.6, U12.14 (PA0)
/OnStep_MaxSTM/M: J1.A7 (D-), J1.B7 (D-), U2.5 (D-), U5.1 (I/O1)
/OnStep_MaxSTM/NRST: C5.1, R2.1, U12.7 (NRST)
/OnStep_MaxSTM/ONEWIRE: J18.2, R19.1, U12.51 (PC10)
/OnStep_MaxSTM/OSC32_IN: C8.1, U12.3 (PC14), Y2.1
/OnStep_MaxSTM/OSC32_OUT: C9.1, U12.4 (PC15), Y2.2
/OnStep_MaxSTM/OSCIN: C1.1, R1.1, U12.5 (PH0), Y1.1
/OnStep_MaxSTM/OSCOUT: C4.1, R1.2, U12.6 (PH1), Y1.3
/OnStep_MaxSTM/P: J1.A6 (D+), J1.B6 (D+), U2.4 (D+), U5.3 (I/O2)
/OnStep_MaxSTM/PEC_SENSE: U6.8, U12.62 (PB9)
/OnStep_MaxSTM/RX1: U2.26 (TXD), U12.43 (PA10)
/OnStep_MaxSTM/SCL: J15.3, R17.1, U9.1 (SCL), U12.58 (PB6)
/OnStep_MaxSTM/SDA: J15.2, R16.1, U9.3 (SDA), U12.59 (PB7)
/OnStep_MaxSTM/ST4_DEC_N: D5.2 (A2), J2.5, R23.1, U12.9 (PC1)
/OnStep_MaxSTM/ST4_DEC_S: D4.2 (A2), J2.4, R22.1, U12.10 (PC2)
/OnStep_MaxSTM/ST4_RA_E: D6.2 (A2), J2.6, R24.1, U12.11 (PC3)
/OnStep_MaxSTM/ST4_RA_W: D3.2 (A2), J2.3, R20.1, U12.8 (PC0)
/OnStep_MaxSTM/STATUS_LED: R9.1, U12.2 (PC13)
/OnStep_MaxSTM/SWCLK: TP2.1, U12.49 (PA14)
/OnStep_MaxSTM/SWDIO: TP1.1, U12.46 (PA13)
/OnStep_MaxSTM/TX1: U2.25 (RXD), U12.42 (PA9)
/OnStep_MaxSTM/VBATT: C47.1, D13.3, U12.1 (VBAT)
/OnStep_MaxSTM/VBUS: C25.2, J1.A4 (VBUS), J1.A9 (VBUS), J1.B4 (VBUS), J1.B9 (VBUS), U2.7 (VREGIN), U2.8 (VBUS), U5.5 (VBUS)
/OnStep_MaxSTM/VREF: C7.1, C46.1, L3.2, U12.13 (VDDA)
/PPS: J7.4, R34.1, U12.61 (PB8)
/VBAT: BT1.1 (+), D13.1
GND: A1.1 (GND), A1.7 (GND), A2.1 (GND), A2.7 (GND), BT1.2 (-), C1.2, C2.2, C3.1, C4.2, C5.2, C6.2, C7.2, C8.2, C9.2, C10.2, C11.2, C12.2, C13.1, C14.1, C15.1, C16.1, C18.1, C19.2, C20.2, C21.2, C22.1, C25.1, C26.2, C27.2, C28.2, C40.2, C41.1, C42.2, C43.2, C44.2, C46.2, C47.2, C49.1, D2.2 (A), D3.1 (A1), D4.1 (A1), D5.1 (A1), D6.1 (A1), D8.1 (A1), D9.1 (A1), D10.1 (A1), D14.1 (A1), D17.1 (K), J1.A1 (GND), J1.A12 (GND), J1.B1 (GND), J1.B12 (GND), J2.2, J3.2, J4.1, J5.1, J6.1, J7.1, J8.2, J15.1, J16.1, J17.1, J18.1, R4.1, R6.1, R7.2, R8.2, R15.1, R21.1, R36.1, R37.1, R39.1, R43.2, TP3.1, U1.8 (GND), U2.3 (GND), U2.29 (GND), U5.2 (GND), U6.7 (GND), U7.2 (GND), U8.2 (GND), U9.2 (V_{SS}), U12.12 (VSSA), U12.18 (VSS), U12.31 (VSS), U12.47 (VSS), U12.63 (VSS), Y1.2, Y1.4
unnamed: A1.4 (1A), J11.2, J13.3
unnamed: A1.3 (1B), J11.1, J13.4
unnamed: A1.5 (2A), J11.3, J13.2
unnamed: A1.6 (2B), J11.4, J13.1
unnamed: A1.12 (CFG3), JP1.2 (C)
unnamed: A1.14 (CLK), R36.2
unnamed: A2.4 (1A), J12.2, J14.3
unnamed: A2.3 (1B), J12.1, J14.4
unnamed: A2.5 (2A), J12.3, J14.2
unnamed: A2.6 (2B), J12.4, J14.1
unnamed: A2.12 (CFG3), JP2.2 (C)
unnamed: A2.14 (CLK), R37.2
unnamed: C11.1, F1.1, J2.1
unnamed: D1.1 (K), R9.2
unnamed: C17.2, D2.1 (K), L2.1, U8.6 (SW)
unnamed: D7.2 (A), Q1.4 (G), R21.2
unnamed: D8.2 (A2), J4.2, R25.1, U6.1
unnamed: D9.2 (A2), J5.2, R26.1, U6.3
unnamed: D10.2 (A2), J6.2, R27.1, U6.5
unnamed: D11.2 (A), Q2.4 (G), R31.1, R32.2
unnamed: D14.2 (A2), J17.2, R33.1, U6.9
unnamed: D15.1 (K), R18.2
unnamed: C24.2, D16.2 (A), D17.3 (K), J10.1, R43.1, R44.1, R45.2
unnamed: C24.1, D7.1 (K), D16.1 (K), J10.2, Q1.1 (S), Q1.2 (S), Q1.3 (S), Q4.1 (S), Q4.2 (S), Q4.3 (S)
unnamed: C23.1, D17.2 (A), R45.1
unnamed: J1.A5 (CC1), R7.1
unnamed: J1.B5 (CC2), R8.1
unnamed: J3.1, Q1.5 (D), Q1.6 (D), Q1.7 (D), Q1.8 (D)
unnamed: J8.1, Q2.5 (D), Q2.6 (D), Q2.7 (D), Q2.8 (D)
unnamed: J16.2, R35.1
unnamed: Q3.3 (C), R32.1
unnamed: Q4.4 (G), R44.2
unnamed: R3.1, R29.1, U1.10 (IO0)
unnamed: R5.1, R18.1, U1.9 (IO2)
unnamed: R28.2, U1.15 (RST)
unnamed: C26.1, C27.1, U2.6 (VDD)
unnamed: R39.2, U2.11 (~SUSPEND)
unnamed: R11.1, U7.3 (EN)
unnamed: C17.1, U8.1 (BS)
unnamed: R10.1, U8.4 (EN)
unnamed: R14.1, R15.2, U8.3 (FB)
unnamed: R4.2, U12.28 (PB2)
unnamed: R42.2, U12.29 (PB10)
unnamed: C6.1, U12.30 (VCAP_1)

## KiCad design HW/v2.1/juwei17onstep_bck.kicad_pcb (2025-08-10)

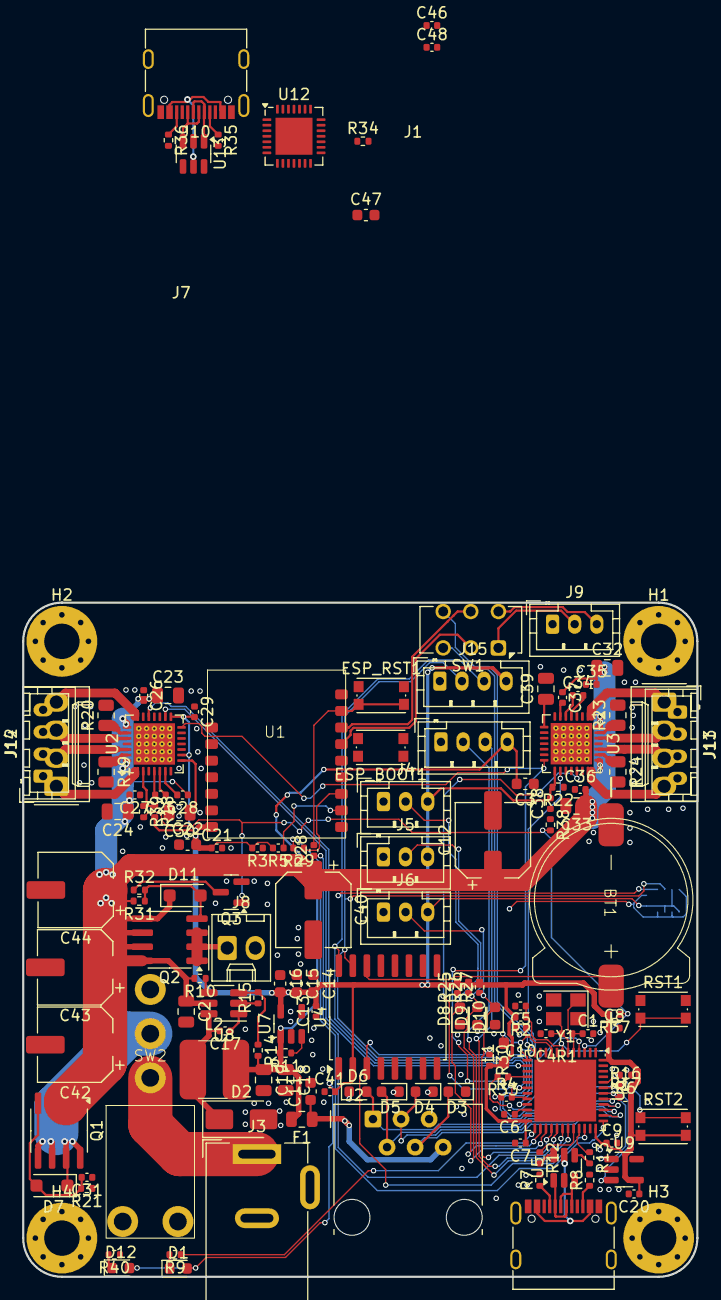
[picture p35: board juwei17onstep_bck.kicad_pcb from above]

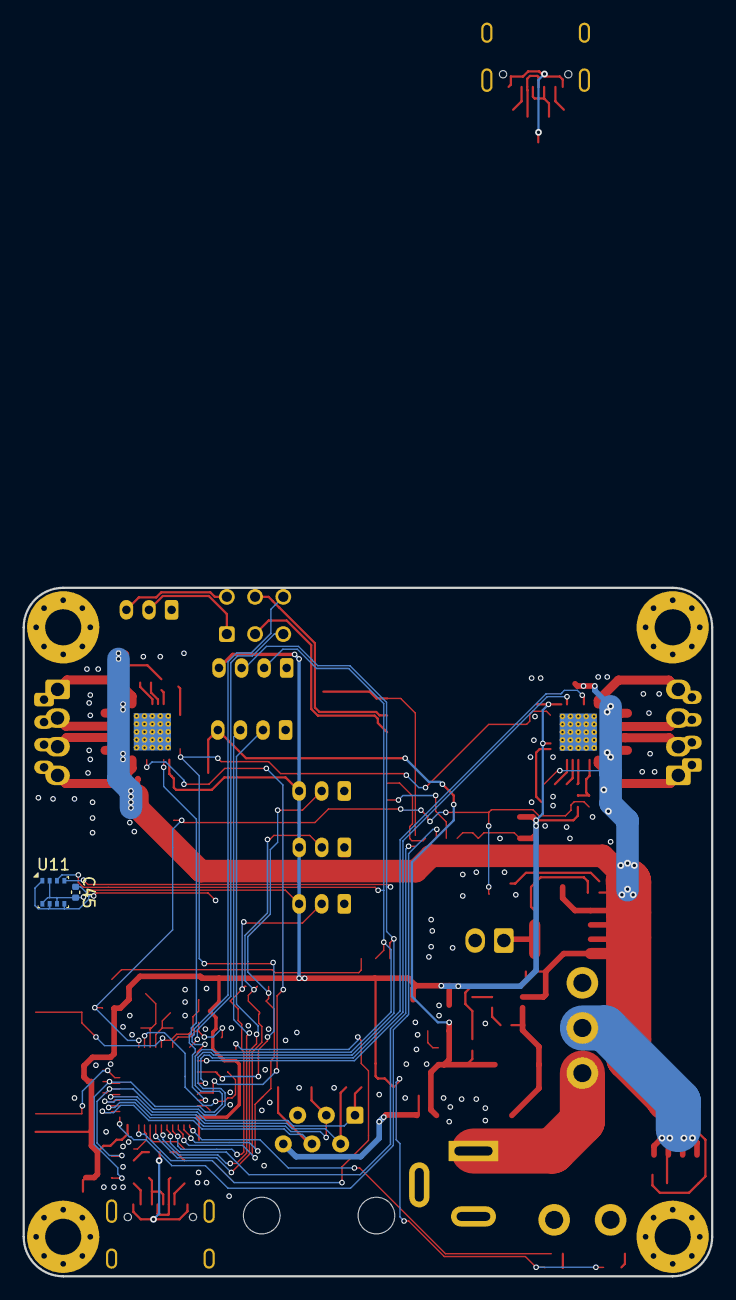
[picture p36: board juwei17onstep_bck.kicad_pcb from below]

Board: 2 copper layers, 61.0 x 61.0 mm, 145 parts (2 on the bottom side), 96 nets.

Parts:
BT1: Battery_Cell; CR1220_holder
C1, C4: 20pF; C_0402_1005Metric
C2, C18, C19: 10u/25V; C_0805_2012Metric
C3, C11, C14, C15, C16, C22, C47: 10uF/10V; C_0603_1608Metric
C5, C13: 1uF/10V; C_0402_1005Metric
C6: 2u2/6.3; C_0402_1005Metric
C7, C8, C9, C10, C20, C21: 100n; C_0402_1005Metric
C12, C40, C42, C43, C44: 100uF/35V; CP_Elec_6.3x7.7
C17: 100n/50V/0603; C_0402_1005Metric
C23, C24, C30, C32, C33, C39: 4.7u/25V; C_0805_2012Metric
C25, C31, C34: 22n/50V; C_0402_1005Metric
C26, C27, C28, C29, C35, C36, C37, C38, C41: 100n/50V; C_0402_1005Metric
C45, C48: 100nF; C_0402_1005Metric
C46: 1uF; C_0402_1005Metric
D1, D12: LED; LED_0603_1608Metric
D2: SS34; D_SMA
D3, D4, D5, D6, D8, D9, D10: 0603ESDA-05N; D_0603_1608Metric
D7: BZT52B12; D_SOD-123F
D11: BZT52Bxx; D_SOD-123F
ESP_BOOT1: EVQPUM; SW_Push_1P1T_NO_CK_KMR2
ESP_RST1: EVQPUM; SW_Push_1P1T_NO_CK_KMR2
F1: SMD0805P050TF; Fuse_0805_2012Metric
H1, H2, H3, H4: MountingHole; MountingHole_3.2mm_M3_Pad_Via
J1, J10: USB_C_Receptacle_USB2.0; USB_C_Receptacle_G-Switch_GT-USB-7010ASV
J2: RJ12; RJ12_Amphenol_54601-x06_Horizontal
J3: 5.5/2.1 Barell DC3; BarrelJack_Wuerth_6941xx301002
J4: RA_HOME; JST_PH_B3B-PH-K_1x03_P2.00mm_Vertical
J5: DEC_HOME; JST_PH_B3B-PH-K_1x03_P2.00mm_Vertical
J6: LIMIT; JST_PH_B3B-PH-K_1x03_P2.00mm_Vertical
J7: GPS; JST_PH_B4B-PH-K_1x04_P2.00mm_Vertical
J8: Conn_01x02; Molex_KK-254_AE-6410-02A_1x02_P2.54mm_Vertical
J9: ESP_UART; JST_PH_B3B-PH-K_1x03_P2.00mm_Vertical
J11, J12: RA_2mm; JST_PH_B4B-PH-K_1x04_P2.00mm_Vertical
J13, J14: RA_2.54mm; Molex_KK-254_AE-6410-04A_1x04_P2.54mm_Vertical
J15: I2C; JST_PH_B4B-PH-K_1x04_P2.00mm_Vertical
L1: BLM18HE601SH1D; L_0603_1608Metric_Pad1.05x0.95mm_HandSolder
L2: FNR5040S100MT; L_5.5x5.1mm
Q1, Q2: AO4411; SOIC-8_3.9x4.9mm_P1.27mm
Q3: DTC114E; SOT-23
R1: 1MEG; C_0402_1005Metric
R2, R3, R4, R5: 10k; C_0402_1005Metric
R6, R21, R25, R26, R27, R34: 10k; R_0402_1005Metric
R7, R8, R35, R36: 5k1; R_0402_1005Metric
R9, R38, R39, R40: 1k; R_0402_1005Metric
R10, R11, R18, R22, R31, R37: 100k; R_0402_1005Metric
R12, R13: 22R; R_0402_1005Metric
R14: 36k; R_0402_1005Metric
R15: 6k8; R_0402_1005Metric
R16, R17, R30, R32: 4k7; R_0402_1005Metric
R19, R20, R23, R24: 0.11R/0805; R_0805_2012Metric
R28, R29, R33: 1k; C_0402_1005Metric
RST1, RST2: EVQPUM; SW_Push_1P1T_NO_CK_KMR2
SW1: SW_Slide_DPDT; SW_CK_JS202011CQN_DPDT_Straight
SW2: SW_SPST; MTS-102-C4
U1: ESP_M2
U2, U3: QFN-28-1EP_5x5mm_P0.5mm_EP3.75x3.75mm_ThermalVias
U4: DS3231M; SOIC-16W_7.5x10.3mm_P1.27mm
U5, U13: USBLC6-2SC6; SOT-23-6
U6: STM32F411CCUx; QFN-48-1EP_7x7mm_P0.5mm_EP5.6x5.6mm
U7: ME6211; SOT-23-5
U8: ME3116; SOT-23-6_Handsoldering
U9: 24AA64T-I/OT; SOT-23-5
U11: BME280; Bosch_LGA-8_2.5x2.5mm_P0.65mm_ClockwisePinNumbering
U12: CP2102N-Axx-xQFN28; QFN-28-1EP_5x5mm_P0.5mm_EP3.35x3.35mm
Y1: TAXM8M4RDBCCT2T / 8MHz 3225; Crystal_SMD_3225-4Pin_3.2x2.5mm

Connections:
/3V3: C7.1, C8.1, C9.1, C13.2, C14.2, C15.2, C16.2, C20.1, C21.1, C22.2, C29.2, C38.2, C41.2, C45.2, D1.2 (A), D12.2 (A), J4.3, J5.3, J6.3, J15.4, L1.1, R2.2, R3.2, R5.2, R16.2, R17.2, R18.2, R22.2, R25.2, R26.2, R27.2, R30.2, R37.2, RST2.2, U1.7 (VCC), U2.9 (MS1_AD0), U2.15 (VCC_IO), U3.15 (VCC_IO), U4.2 (VCC), U6.24 (VDD), U6.36 (VDD), U6.48 (VDD), U7.5 (OUT), U9.4 (V_{CC}), U11.2 (CSB), U11.6 (VDDIO), U11.8 (VDD)
/DEC/DIR: U2.19 (DIR), U6.18 (PB0)
/DEC/ENN: Q3.1 (B), R37.1, R38.2, R39.2, U6.3 (PC14)
/DEC/OUTA1: J12.3, J14.3, U2.24 (OUTA1)
/DEC/OUTA2: J12.4, J14.4, U2.21 (OUTA2)
/DEC/OUTB1: J12.2, J14.2, U2.26 (OUTB1)
/DEC/OUTB2: J12.1, J14.1, U2.1 (OUTB2)
/DEC/STEP: U2.16 (STEP), U6.14 (PA4)
/DEC/TMC_UART: R33.1, U2.14 (PDN_UART), U3.14 (PDN_UART), U6.16 (PA6)
/DEC/VM: C2.1, C12.1, C23.1, C24.1, C26.2, C27.2, C28.1, C32.1, C33.1, C35.2, C36.2, C37.1, C40.1, C42.1, C43.1, C44.1, D11.1 (K), Q1.1 (S), Q1.2 (S), Q1.3 (S), Q2.5 (D), Q2.6 (D), Q2.7 (D), Q2.8 (D), R10.2, R31.2, U2.22 (VS), U2.28 (VS), U3.22 (VS), U3.28 (VS), U8.5 (VIN)
/ESP_BOOT: R29.2, U6.37 (PA14)
/ESP_RST: R28.1, U6.29 (PA8)
/ESP_RXD: SW1.4 (A), U6.13 (PA3)
/ESP_TXD: SW1.3 (C), U6.12 (PA2)
/GND: BT1.2 (-), C1.2, C2.2, C3.1, C4.2, C5.2, C6.2, C7.2, C8.2, C9.2, C10.2, C11.2, C12.2, C13.1, C14.1, C15.1, C16.1, C18.2, C19.2, C20.2, C21.2, C22.1, C23.2, C24.2, C26.1, C27.1, C29.1, C30.2, C31.1, C32.2, C33.2, C35.1, C36.1, C38.1, C39.2, C40.2, C41.1, C42.2, C43.2, C44.2, C45.1, C46.1, C47.2, C48.2, D2.2 (A), D3.1 (A1), D4.1 (A1), D5.1 (A1), D6.1 (A1), D8.1 (A1), D9.1 (A1), D10.1 (A1), ESP_BOOT1.1, ESP_RST1.1, J1.A1 (GND), J1.A12 (GND), J1.B1 (GND), J1.B12 (GND), J2.5, J3.2, J4.1, J5.1, J6.1, J7.1, J8.2, J9.1, J10.A1 (GND), J10.A12 (GND), J10.B1 (GND), J10.B12 (GND), J15.1, Q3.2 (E), R4.1, R6.1, R7.2, R8.2, R15.1, R19.2, R20.2, R21.1, R23.2, R24.2, R34.1, R35.2, R36.2, R40.1, RST1.1, U1.8 (GND), U2.3 (GND), U2.10 (MS2_AD1), U2.13 (CLK), U2.18 (GND), U2.29 (GND), U3.3 (GND), U3.9 (MS1_AD0), U3.10 (MS2_AD1), U3.13 (CLK), U3.18 (GND), U3.29 (GND), U4.5 (GND), U4.6 (GND), U4.7 (GND), U4.8 (GND), U4.9 (GND), U4.10 (GND), U4.11 (GND), U4.12 (GND), U4.13 (GND), U5.2 (GND), U6.8 (VSSA), U6.23 (VSS), U6.35 (VSS), U6.47 (VSS), U6.49 (VSS), U7.2 (GND), U8.2 (GND), U9.2 (V_{SS}), U11.1 (GND), U11.5 (SDO), U11.7 (GND), U12.3 (GND), U12.29 (GND), U13.2 (GND), Y1.2, Y1.4
/GPS_RXD: J7.2, U6.31 (PA10)
/GPS_TXD: J7.3, U6.30 (PA9)
/ME3116/VOUT: C3.2, C18.1, C19.1, F1.2, J7.4, L2.2, R11.2, R14.2, U7.1 (IN)
/OnStep_MaxSTM/AXIS1_DIR: R4.2, U3.19 (DIR), U6.20 (PB2)
/OnStep_MaxSTM/AXIS1_HOME_SW: D8.2 (A2), J4.2, R25.1, U6.26 (PB13)
/OnStep_MaxSTM/AXIS1_STEP: U3.16 (STEP), U6.21 (PB10)
/OnStep_MaxSTM/AXIS2_HOME_SW: D9.2 (A2), J5.2, R26.1, U6.27 (PB14)
/OnStep_MaxSTM/BOOT0: R6.2, RST2.1, U6.44 (BOOT0)
/OnStep_MaxSTM/DM: R12.2, U5.6 (I/O1)
/OnStep_MaxSTM/DP: R13.2, U5.4 (I/O2)
/OnStep_MaxSTM/LIMIT_SW: D10.2 (A2), J6.2, R27.1, U6.28 (PB15)
/OnStep_MaxSTM/NRST: C5.1, R2.1, RST1.2, U6.7 (NRST)
/OnStep_MaxSTM/OSCIN: C1.1, R1.1, U6.5 (PH0), Y1.1
/OnStep_MaxSTM/OSCOUT: C4.1, R1.2, U6.6 (PH1), Y1.3
/OnStep_MaxSTM/PPS_SENSE: R30.1, U4.3 (~INT/SQW), U6.34 (PA13)
/OnStep_MaxSTM/SCL: J15.3, R17.1, U4.16 (SCL), U6.42 (PB6), U9.1 (SCL), U11.4 (SCK)
/OnStep_MaxSTM/SDA: J15.2, R16.1, U4.15 (SDA), U6.43 (PB7), U9.3 (SDA), U11.3 (SDI)
/OnStep_MaxSTM/ST4_DEC_N: D5.2 (A2), J2.2, U6.40 (PB4)
/OnStep_MaxSTM/ST4_DEC_S: D4.2 (A2), J2.3, U6.39 (PB3)
/OnStep_MaxSTM/ST4_RA_E: D6.2 (A2), J2.1, U6.41 (PB5)
/OnStep_MaxSTM/ST4_RA_W: D3.2 (A2), J2.4, U6.38 (PA15)
/OnStep_MaxSTM/STATUS_LED: R9.1, U6.25 (PB12)
/OnStep_MaxSTM/VREF: C10.1, L1.2, U6.9 (VDDA)
/RA/OUTA1: J11.3, J13.3, U3.24 (OUTA1)
/RA/OUTA2: J11.4, J13.4, U3.21 (OUTA2)
/RA/OUTB1: J11.2, J13.2, U3.26 (OUTB1)
/RA/OUTB2: J11.1, J13.1, U3.1 (OUTB2)
/esp_m1/RX1: J9.2, SW1.1 (A), U12.26 (TXD)
/esp_m1/RXD0: SW1.2 (B), U1.13 (RXD0)
/esp_m1/TX1: J9.3, SW1.6 (C), U12.25 (RXD)
/esp_m1/TXD0: SW1.5 (B), U1.14 (TXD0)
/esp_m1/VBUS: C46.2, J10.A4 (VBUS), J10.A9 (VBUS), J10.B4 (VBUS), J10.B9 (VBUS), U12.7 (VREGIN), U12.8 (VBUS), U13.5 (VBUS)
/i2c_per/VBAT: BT1.1 (+), U4.14 (VBAT)
unnamed: C11.1, F1.1, J2.6
unnamed: D1.1 (K), R9.2
unnamed: C17.2, D2.1 (K), L2.1, U8.6 (SW)
unnamed: C31.2, D7.2 (A), Q1.4 (G), R21.2
unnamed: D7.1 (K), Q1.5 (D), Q1.6 (D), Q1.7 (D), Q1.8 (D), SW2.2 (B)
unnamed: D11.2 (A), Q2.4 (G), R31.1, R32.2
unnamed: D12.1 (K), R40.2
unnamed: J1.A5 (CC1), R7.1
unnamed: J1.B5 (CC2), R8.1
unnamed: J1.A6 (D+), J1.B6 (D+), U5.3 (I/O2)
unnamed: J1.A7 (D-), J1.B7 (D-), U5.1 (I/O1)
unnamed: J8.1, Q2.1 (S), Q2.2 (S), Q2.3 (S)
unnamed: J10.A5 (CC1), R35.1
unnamed: J10.B5 (CC2), R36.1
unnamed: J10.A6 (D+), J10.B6 (D+), U13.3 (I/O2)
unnamed: J10.A7 (D-), J10.B7 (D-), U13.1 (I/O1)
unnamed: Q3.3 (C), R32.1
unnamed: J3.1, SW2.1 (A)
unnamed: ESP_BOOT1.2, R3.1, R29.1, U1.10 (IO0)
unnamed: R5.1, U1.9 (IO2)
unnamed: ESP_RST1.2, R28.2, U1.15 (RST)
unnamed: C30.1, U2.8 (5VOUT)
unnamed: R20.1, U2.23 (BRA)
unnamed: R19.1, U2.27 (BRB)
unnamed: C25.1, U2.5 (CPI)
unnamed: C25.2, U2.4 (CPO)
unnamed: R18.1, R39.1, U2.2 (ENN)
unnamed: C28.2, U2.6 (VCP)
unnamed: C39.1, U3.8 (5VOUT)
unnamed: R24.1, U3.23 (BRA)
unnamed: R23.1, U3.27 (BRB)
unnamed: C34.1, U3.5 (CPI)
unnamed: C34.2, U3.4 (CPO)
unnamed: R22.1, R38.1, U3.2 (ENN)
unnamed: C37.2, U3.6 (VCP)
unnamed: J1.A4 (VBUS), J1.A9 (VBUS), J1.B4 (VBUS), J1.B9 (VBUS), U5.5 (VBUS)
unnamed: R12.1, U6.32 (PA11)
unnamed: R13.1, U6.33 (PA12)
unnamed: R33.2, U6.4 (PC15)
unnamed: C6.1, U6.22 (VCAP1)
unnamed: R11.1, U7.3 (EN)
unnamed: C17.1, U8.1 (BS)
unnamed: R10.1, U8.4 (EN)
unnamed: R14.1, R15.2, U8.3 (FB)
unnamed: U12.4 (D+), U13.4 (I/O2)
unnamed: U12.5 (D-), U13.6 (I/O1)
unnamed: C47.1, C48.1, U12.6 (VDD)
unnamed: R34.2, U12.11 (~SUSPEND)

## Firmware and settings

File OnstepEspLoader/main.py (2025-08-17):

import tkinter as tk
from tkinter import ttk, messagebox
import serial.tools.list_ports
import subprocess

class OnstepEspLoaderApp(tk.Tk):

    def __init__(self):
        super().__init__()
        self.title("OnstepEspLoader")
        self.geometry("700x500")
        self.resizable(True, True)

        # --- Top: STM32 firmware selection ---
        top_frame = ttk.Frame(self)
        top_frame.pack(pady=(10, 0), fill=tk.X)

        self.own_firmware_var = tk.BooleanVar(value=False)
        own_fw_cb = ttk.Checkbutton(top_frame, text="Own STM32 firmware", variable=self.own_firmware_var, command=self.on_own_firmware_toggle)
        own_fw_cb.pack(side=tk.LEFT, padx=(5, 10))

        # Browse button and firmware path textbox
        self.firmware_path_var = tk.StringVar()
        self.browse_btn = ttk.Button(top_frame, text="Browse", command=self.browse_firmware, state="disabled")
        self.browse_btn.pack(side=tk.LEFT)
        self.firmware_entry = ttk.Entry(top_frame, textvariable=self.firmware_path_var, width=40, state="readonly")
        self.firmware_entry.pack(side=tk.LEFT, padx=5)

        # Filename to be uploaded (caption/non-editable)
        self.upload_filename_var = tk.StringVar()
        filename_frame = ttk.Frame(self)
        filename_frame.pack(pady=(2, 0), fill=tk.X)
        ttk.Label(filename_frame, text="Firmware to be uploaded:").pack(side=tk.LEFT, padx=(10, 5))
        self.upload_filename_entry = ttk.Entry(filename_frame, textvariable=self.upload_filename_var, width=45, state="readonly")
        self.upload_filename_entry.pack(side=tk.LEFT)

        # TMC radio buttons and homing checkbox (below Browse)
        tmc_homing_frame = ttk.Frame(self)
        tmc_homing_frame.pack(pady=(0, 0), fill=tk.X)
        self.tmc_var = tk.StringVar(value="TMC2209")
        self.homing_var = tk.BooleanVar(value=True)
        self.tmc_var.trace_add("write", lambda *args: self.update_upload_filename())
        self.homing_var.trace_add("write", lambda *args: self.update_upload_filename())
        self.tmc_frame = ttk.LabelFrame(tmc_homing_frame, text="TMC Module")
        self.tmc_radio_2209 = ttk.Radiobutton(self.tmc_frame, text="TMC2209", variable=self.tmc_var, value="TMC2209")
        self.tmc_radio_2130 = ttk.Radiobutton(self.tmc_frame, text="TMC2130", variable=self.tmc_var, value="TMC2130")
        self.tmc_radio_5160 = ttk.Radiobutton(self.tmc_frame, text="TMC5160", variable=self.tmc_var, value="TMC5160")
        self.tmc_radio_2209.pack(side=tk.LEFT, padx=2)
        self.tmc_radio_2130.pack(side=tk.LEFT, padx=2)
        self.tmc_radio_5160.pack(side=tk.LEFT, padx=2)
        self.tmc_frame.pack(side=tk.LEFT, padx=10)
        self.homing_cb = ttk.Checkbutton(tmc_homing_frame, text="Enable Homing", variable=self.homing_var)
        self.homing_cb.pack(side=tk.LEFT, padx=10)

        # Serial port selection
        self.serial_ports = self.get_serial_ports()
        self.selected_port = tk.StringVar()
        port_frame = ttk.Frame(self)
        port_frame.pack(pady=(15, 0))
        ttk.Label(port_frame, text="Select Serial Port:").pack(side=tk.LEFT)
        self.port_combo = ttk.Combobox(port_frame, textvariable=self.selected_port, values=self.serial_ports, state="readonly", width=30)
        self.port_combo.pack(side=tk.LEFT, padx=5)
        ttk.Button(port_frame, text="Refresh", command=self.refresh_ports).pack(side=tk.LEFT)
        if self.serial_ports:
            self.port_combo.current(0)

        # Action buttons
        btn_frame = ttk.Frame(self)
        btn_frame.pack(pady=10)
        ttk.Button(btn_frame, text="Check STM32", command=self.read_stm32_id).pack(side=tk.LEFT, padx=5)
        ttk.Button(btn_frame, text="Upload STM32", command=self.flash_stm32).pack(side=tk.LEFT, padx=5)
        ttk.Button(btn_frame, text="Check OnStepX", command=self.check_onstex).pack(side=tk.LEFT, padx=5)
        ttk.Button(btn_frame, text="SWS Upload Mode", command=self.switch_onstep_mode).pack(side=tk.LEFT, padx=5)
        ttk.Button(btn_frame, text="Upload ESP", command=self.upload_esp8266).pack(side=tk.LEFT, padx=5)

        # Status/console output
        ttk.Label(self, text="Console Output:").pack(pady=(10, 0))
        self.console = tk.Text(self, height=18, width=90, state="disabled", wrap="word", bg="#222", fg="#eee")
        self.console.pack(padx=10, pady=(0, 10), fill=tk.BOTH, expand=True)

        # Initial state
        self.update_upload_filename()
        self.on_own_firmware_toggle()

    def on_own_firmware_toggle(self):
        # Only set 'state' on widgets that support it (Radiobutton, Checkbutton, Button, Entry)
        if self.own_firmware_var.get():
            self.browse_btn.config(state="normal")
            self.firmware_entry.config(state="readonly")
            self.tmc_radio_2209.config(state="disabled")
            self.tmc_radio_2130.config(state="disabled")
            self.tmc_radio_5160.config(state="disabled")
            self.homing_cb.config(state="disabled")
        else:
            self.browse_btn.config(state="disabled")
            self.firmware_entry.config(state="readonly")
            self.tmc_radio_2209.config(state="normal")
            self.tmc_radio_2130.config(state="normal")
            self.tmc_radio_5160.config(state="normal")
            self.homing_cb.config(state="normal")
        self.update_upload_filename()

    def browse_firmware(self):
        from tkinter import filedialog
        file_path = filedialog.askopenfilename(title="Select STM32 Firmware", filetypes=[("Binary Files", "*.bin"), ("All Files", "*.*")])
        if file_path:
            self.firmware_path_var.set(file_path)
        self.update_upload_filename()

    def check_onstex(self):
        import threading
        import serial
        port = self.selected_port.get()
        if not port:
            self.append_console("[ERROR] No serial port selected.")
            return
        self.append_console(f"[INFO] Checking OnStepX firmware on {port} at 9600 baud...")

        def worker():
            try:
                with serial.Serial(port, 9600, timeout=2) as ser:
                    # Send :GVP# to get firmware name
                    ser.write(":GVP#\r\n".encode('ascii'))
                    name_resp = ser.read(256).decode(errors='replace').strip()
                    if name_resp:
                        name_resp = name_resp[:-1]
                    self.append_console(f"[INFO] Firmware name response: {name_resp}")
                    # Send :GVN# to get firmware version
                    ser.write(":GVN#\r\n".encode('ascii'))
                    ver_resp = ser.read(256).decode(errors='replace').strip()
                    if ver_resp:
                        ver_resp = ver_resp[:-1]
                    self.append_console(f"[INFO] Firmware version response: {ver_resp}")
                    # Try to extract and display as 'OnStepX 3.16'
                    name = name_resp.split()[0] if name_resp else "?"
                    version = ver_resp.split()[0] if ver_resp else "?"
                    self.append_console(f"[SUCCESS] {name} {version}")
            except serial.SerialException as e:
                self.append_console(f"[ERROR] Serial error: {e}")
            except Exception as e:
                self.append_console(f"[ERROR] Exception: {e}")

        threading.Thread(target=worker, daemon=True).start()

    def get_serial_ports(self):
        return [port.device for port in serial.tools.list_ports.comports()]

    def refresh_ports(self):
        ports = self.get_serial_ports()
        self.port_combo['values'] = ports
        self.serial_ports = ports
        if ports:
            self.port_combo.current(0)
            self.selected_port.set(ports[0])
        else:
            self.selected_port.set("")

    def append_console(self, text):
        self.console.configure(state="normal")
        self.console.insert(tk.END, text + "\n")
        self.console.see(tk.END)
        self.console.configure(state="disabled")

    def read_stm32_id(self):
        import threading
        port = self.selected_port.get()
        if not port:
            self.append_console("[ERROR] No serial port selected.")
            return
        self.append_console(f"[INFO] Reading STM32 Device ID on {port} using stm32loader CLI...")

        def worker():
            try:
                process = subprocess.Popen([
                    "stm32loader",
                    "-p", port,
                    "-b", "115200",
                    "-f", "F4"
                ], stdout=subprocess.PIPE, stderr=subprocess.STDOUT, text=True, bufsize=1, universal_newlines=True)
                output_lines = []
                for line in process.stdout:
                    line = line.rstrip()
                    output_lines.append(line)
                    self.append_console(line)
                process.wait()
                if process.returncode == 0:
                    self.append_console("[SUCCESS] STM32 check complete.")
                else:
                    self.append_console("[ERROR] STM32 check failed.")
            except FileNotFoundError:
                self.append_console("[ERROR] stm32loader not found. Please ensure it is installed and in your PATH.")
            except Exception as e:
                self.append_console(f"[ERROR] Exception: {e}")

        threading.Thread(target=worker, daemon=True).start()

    def flash_stm32(self):
        import threading
        port = self.selected_port.get()
        # Determine firmware file
        if self.own_firmware_var.get():
            firmware = self.firmware_path_var.get()
            if not firmware:
                self.append_console("[ERROR] No firmware file selected.")
                return
        else:
            tmc = self.tmc_var.get()
            homing = self.homing_var.get()
            if tmc == "TMC5160":
                firmware = "firmware_5160_wH.bin" if homing else "firmware_5160_woH.bin"
            elif tmc == "TMC2130":
                firmware = "firmware_2130_wH.bin" if homing else "firmware_2130_woH.bin"
            else:
                firmware = "firmware_2209_wH.bin" if homing else "firmware_2209_woH.bin"

        if not port:
            self.append_console("[ERROR] No serial port selected.")
            return
        self.append_console(f"[INFO] Flashing STM32 on {port} with {firmware} using stm32loader...")

        def worker():
            try:
                process = subprocess.Popen([
                    "stm32loader",
                    "-p", port,
                    "-b", "115200",
                    "--family", "F4",
                    "--erase",
                    "--write",
                    "--verify",
                    firmware
                ], stdout=subprocess.PIPE, stderr=subprocess.STDOUT, text=True, bufsize=1, universal_newlines=True)
                output_lines = []
                for line in process.stdout:
                    line = line.rstrip()
                    output_lines.append(line)
                    self.append_console(line)
                process.wait()
                if process.returncode == 0:
                    self.append_console("[SUCCESS] Flash and verify complete.")
                    self.append_console("[INFO] Starting OnStepX...")
                    # Run go-address command
                    try:
                        go_proc = subprocess.Popen([
                            "stm32loader",
                            "--family", "F4",
                            "-p", port,
                            "-b", "115200",
                            "--go-address", "0x08000000"
                        ], stdout=subprocess.PIPE, stderr=subprocess.STDOUT, text=True, bufsize=1, universal_newlines=True)
                        for go_line in go_proc.stdout:
                            go_line = go_line.rstrip()
                            self.append_console(go_line)
                        go_proc.wait()
                        if go_proc.returncode == 0:
                            self.append_console("[SUCCESS] OnStepX started.")
                        else:
                            self.append_console("[ERROR] Failed to start OnStepX.")
                    except Exception as e:
                        self.append_console(f"[ERROR] Exception during OnStepX start: {e}")
                else:
                    self.append_console("[ERROR] Flash/verify failed.")
            except FileNotFoundError:
                self.append_console("[ERROR] stm32loader not found. Please ensure it is installed and in your PATH.")
            except Exception as e:
                self.append_console(f"[ERROR] Exception: {e}")

        threading.Thread(target=worker, daemon=True).start()

    def switch_onstep_mode(self):
        import threading
        import serial
        port = self.selected_port.get()
        if not port:
            self.append_console("[ERROR] No serial port selected.")
            return
        self.append_console(f"[INFO] Switching OnStep to SWS Upload Mode on {port} at 9600 baud...")

        def worker():
            try:
                with serial.Serial(port, 9600, timeout=2) as ser:
                    command = ":hF#:ESPFLASH#"
                    ser.write(command.encode('ascii'))
                    self.append_console(f"[INFO] Sent: {command.strip()}")
                    # Read response (up to 256 bytes or until timeout)
                    response = ser.read(256)
                    response_str = response.decode(errors='replace').strip()
                    if response_str:
                        self.append_console(f"[SUCCESS] STM32 response: {response_str}")
                    else:
                        self.append_console("[WARNING] No response from STM32.")
            except serial.SerialException as e:
                self.append_console(f"[ERROR] Serial error: {e}")
            except Exception as e:
                self.append_console(f"[ERROR] Exception: {e}")

        threading.Thread(target=worker, daemon=True).start()

    def upload_esp8266(self):
        import threading
        port = self.selected_port.get()
        firmware = "SmartWebServer.ino.bin"
        if not port:
            self.append_console("[ERROR] No serial port selected.")
            return
        self.append_console(f"[INFO] Flashing ESP8266 on {port} with {firmware} using esptool...")

        def worker():
            import os
            esptool_path = os.path.abspath("esptool.exe")
            # Common parameters for ESP8266 flashing
            # Example: esptool.exe --port COMx --baud 115200 write_flash --flash_size detect 0x00000 SmartWebServer.ino.bin
            try:
                process = subprocess.Popen([
                    esptool_path,
                    "--port", port,
                    "--baud", "115200",
                    "write_flash",
                    "--flash_size", "detect",
                    "0x00000", firmware
                ], stdout=subprocess.PIPE, stderr=subprocess.STDOUT, text=True, bufsize=1, universal_newlines=True)
                for line in process.stdout:
                    line = line.rstrip()
                    self.append_console(line)
                process.wait()
                if process.returncode == 0:
                    self.append_console("[SUCCESS] ESP8266 flash complete. Now turn OnStepX off and on again to start the new firmware.")
                else:
                    self.append_console("[ERROR] ESP8266 flash failed.")
            except FileNotFoundError:
                self.append_console("[ERROR] esptool.exe not found. Please ensure it is in the application directory.")
            except Exception as e:
                self.append_console(f"[ERROR] Exception: {e}")

        threading.Thread(target=worker, daemon=True).start()

    def update_upload_filename(self):
        if self.own_firmware_var.get():
            import os
            path = self.firmware_path_var.get()
            filename = os.path.basename(path) if path else ""
        else:
            tmc = self.tmc_var.get()
            homing = self.homing_var.get()
            if tmc == "TMC5160":
                filename = "firmware_5160_wH.bin" if homing else "firmware_5160_woH.bin"
            elif tmc == "TMC2130":
                filename = "firmware_2130_wH.bin" if homing else "firmware_2130_woH.bin"
            else:
                filename = "firmware_2209_wH.bin" if homing else "firmware_2209_woH.bin"
        self.upload_filename_var.set(filename)


if __name__ == "__main__":
    app = OnstepEspLoaderApp()
    app.mainloop()

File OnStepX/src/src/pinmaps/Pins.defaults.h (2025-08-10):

// -------------------------------------------------------------------------------------------------
// Null pin map, assigns OFF to all values not already assigned
#pragma once

// --------------------------------------------------------------------------------------------------------
// Serial, SPI, and I2C interface pins

// usually the default serial port
#if SERIAL_A_BAUD_DEFAULT != OFF
#ifndef SERIAL_A
#define SERIAL_A                    Serial
#endif
#endif

// automatic setup of serial passthrough
#if SERIAL_B_ESP_FLASHING == ON
#define SERIAL_PASSTHROUGH SERIAL_B
#define SERIAL_PASSTHROUGH_BAUD_DEFAULT SERIAL_B_BAUD_DEFAULT
#define SERIAL_INPUT SERIAL_A
#define SERIAL_INPUT_BAUD_DEFAULT SERIAL_A_BAUD_DEFAULT

#ifdef SERIAL_B_RX
#define SERIAL_PASSTHROUGH_RX SERIAL_B_RX
#endif
#ifdef SERIAL_B_TX
#define SERIAL_PASSTHROUGH_TX SERIAL_B_TX
#endif
#ifdef SERIAL_B_RXTX_SET
#define SERIAL_PASSTHROUGH_RXTX_SET SERIAL_B_RXTX_SET
#endif

#ifdef SERIAL_C_RX
#define SERIAL_INPUT_RX SERIAL_C_RX
#endif
#ifdef SERIAL_C_TX
#define SERIAL_INPUT_TX SERIAL_C_TX
#endif
#ifdef SERIAL_C_RXTX_SET
#define SERIAL_INPUT_RXTX_SET SERIAL_C_RXTX_SET
#endif
#endif

// default settings for any TMC UART drivers that may be present
#if defined(STEP_DIR_TMC_UART_PRESENT)
#ifndef SERIAL_TMC
#define SERIAL_TMC                  SoftSerial     // Use software serial with TX on M3 (CS) of each axis
#endif
#ifndef SERIAL_TMC_RX_DISABLE
#define SERIAL_TMC_RX_DISABLE       true           // Recieving data often doesn't work with software serial
#endif
#ifndef SERIAL_TMC_BAUD
#define SERIAL_TMC_BAUD             115200         // Baud rate
#endif
#ifndef SERIAL_TMC_ADDRESS_MAP
#define SERIAL_TMC_ADDRESS_MAP(x)   (0)            // driver addresses are 0 for all axes
#endif
#ifndef SERIAL_TMC_INVERT
#define SERIAL_TMC_INVERT           OFF            // invert the serial interface signal logic
#endif
#endif

// pin# for controlling the reset of W5500 so it comes up properly
#ifndef ETHERNET_RESET_PIN
#define ETHERNET_RESET_PIN          OFF
#endif

// Specify the default I2C pins (if they can be set via the HAL)
#ifndef I2C_SDA_PIN
#define I2C_SDA_PIN                 OFF
#endif

#ifndef I2C_SCL_PIN
#define I2C_SCL_PIN                 OFF
#endif

// --------------------------------------------------------------------------------------------------------
// GPIO SSR74HC595 pins
#ifndef GPIO_SSR74HC595_LATCH_PIN
#define GPIO_SSR74HC595_LATCH_PIN   OFF            // If used, only pins 0 to 31 are supported on the ESP32
#endif

#ifndef GPIO_SSR74HC595_CLOCK_PIN
#define GPIO_SSR74HC595_CLOCK_PIN   OFF            // If used, only pins 0 to 31 are supported on the ESP32
#endif

#ifndef GPIO_SSR74HC595_DATA_PIN
#define GPIO_SSR74HC595_DATA_PIN    OFF            // If used, only pins 0 to 31 are supported on the ESP32
#endif

#ifndef GPIO_SSR74HC595_COUNT
#define GPIO_SSR74HC595_COUNT       8              // 8, 16, 24, or 32 (for 1, 2, 3, or 4 74HC595's)
#endif

// --------------------------------------------------------------------------------------------------------
// define standard pins as inactive
#ifndef AUX0_PIN
#define AUX0_PIN                    OFF
#endif

#ifndef AUX1_PIN
#define AUX1_PIN                    OFF
#endif

#ifndef AUX2_PIN
#define AUX2_PIN                    OFF
#endif

#ifndef AUX3_PIN
#define AUX3_PIN                    OFF
#endif

#ifndef AUX4_PIN
#define AUX4_PIN                    OFF
#endif

#ifndef AUX5_PIN
#define AUX5_PIN                    OFF
#endif

#ifndef AUX6_PIN
#define AUX6_PIN                    OFF
#endif

#ifndef AUX7_PIN
#define AUX7_PIN                    OFF
#endif

#ifndef AUX8_PIN
#define AUX8_PIN                    OFF
#endif

#ifndef ONE_WIRE_PIN
#define ONE_WIRE_PIN                OFF
#endif

#ifndef ADDON_TRIGR_PIN
#define ADDON_TRIGR_PIN             OFF
#endif

#ifndef ADDON_SELECT_PIN
#define ADDON_SELECT_PIN            OFF
#endif

#ifndef ADDON_GPIO0_PIN
#define ADDON_GPIO0_PIN             OFF
#endif

#ifndef ADDON_RESET_PIN
#define ADDON_RESET_PIN             OFF
#endif

#ifndef PARK_SENSE_PIN
#define PARK_SENSE_PIN              OFF
#endif

#ifndef PARK_SIGNAL_PIN
#define PARK_SIGNAL_PIN             OFF
#endif

#ifndef PARK_STATUS_PIN
#define PARK_STATUS_PIN             OFF
#endif

#ifndef PEC_SENSE_PIN
#define PEC_SENSE_PIN               OFF
#endif

#ifndef STATUS_LED_PIN
#define STATUS_LED_PIN              OFF
#endif

#ifndef MOUNT_LED_PIN
#define MOUNT_LED_PIN               OFF
#endif

#ifndef RETICLE_LED_PIN
#define RETICLE_LED_PIN             OFF
#endif

#ifndef STATUS_BUZZER_PIN
#define STATUS_BUZZER_PIN           OFF
#endif

#ifndef PPS_SENSE_PIN
#define PPS_SENSE_PIN               OFF
#endif

#ifndef LIMIT_SENSE_PIN
#define LIMIT_SENSE_PIN             OFF
#endif
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

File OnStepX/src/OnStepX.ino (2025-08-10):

/*
 * Title       OnStepX
 * by          Howard Dutton
 *
 * Copyright (C) 2021-2024 Howard Dutton
 *
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
 * Description:
 *   Full featured telescope control for
 *   Equatorial and Alt-Az mounts
 *   Rotator
 *   Focusers
 *   Accessories (automatic covers, dew heaters, etc.)
 *
 * Author: Howard Dutton
 *   http://www.stellarjourney.com
 *   hjd1964@gmail.com
 *
 * Revision history, and newer versions:
 *   See GitHub: https://github.com/hjd1964/OnStep
 *
 * Documentation:
 *   https://groups.io/g/onstep/wiki/home
 *
 * Discussion, Questions, ...etc
 *   https://groups.io/g/onstep
 */

// Use tabs "Config..." to configure OnStep to your requirements

// Firmware version ----------------------------------------------------------------------------------------------------------------
#define FirmwareName                "On-Step"
#define FirmwareVersionMajor        10
#define FirmwareVersionMinor        25     // minor version 00 to 99
#define FirmwareVersionPatch        "p"    // for example major.minor patch: 10.03c
#define FirmwareVersionConfig       6      // internal, for tracking configuration file changes



#include "src/Common.h"
#include "src/Validate.h"
#include "src/lib/nv/Nv.h"
#include "src/lib/sense/Sense.h"
#include "src/lib/tasks/OnTask.h"

#include "src/telescope/Telescope.h"
extern Telescope telescope;

HardwareSerial Serial3(PC5,PB10);
HardwareSerial Serial1(PA10,PA9);

#include "src/plugins/Plugins.config.h"

#if DEBUG == PROFILER
  extern void profiler();
#endif

void systemServices() {
  if (!xBusy) nv.poll(false);
}

void sensesPoll() {
  sense.poll();
}

void setup() {
  #if ADDON_SELECT_PIN != OFF
    pinMode(ADDON_SELECT_PIN, OUTPUT);
    digitalWrite(ADDON_SELECT_PIN, HIGH);
  #endif

  #if DEBUG != OFF
    SERIAL_DEBUG.begin(SERIAL_DEBUG_BAUD);
    delay(2000);
  #endif

  // let any special processing the pinmap needs happen
  #ifdef PIN_INIT
    PIN_INIT();
  #endif

  // say hello
  VLF("");
  VF("MSG: OnStepX, version "); V(FirmwareVersionMajor); V("."); V(FirmwareVersionMinor); VL(FirmwareVersionPatch);
  VF("MSG: OnStepX, MCU "); VLF(MCU_STR);
  VF("MSG: OnStepX, pinmap "); VLF(PINMAP_STR);

  // start low level hardware
  VLF("MSG: System, HAL initialize");
  HAL_INIT();

  if (!nv.init()) {
    DLF("WRN: Setup, NV (EEPROM/FRAM/Flash/etc.) device not found!");
    nv.initError = true;
  }
  delay(2000);

  // start system service task
  VF("MSG: System, start NV service task (rate 10ms priority 7)... ");
  // add task for system services, runs at 10ms intervals so commiting 1KB of NV takes about 10 seconds
  // the cache is scanned (for writing) at 2000 bytes/second but can be slower while reading data into the cache at startup
  if (tasks.add(10, 0, true, 7, systemServices, "SysNv")) { VLF("success"); } else { VLF("FAILED!"); }

  // start input sense polling task
  int pollingRate = round((1000.0F/HAL_FRACTIONAL_SEC)/2.0F);
  if (pollingRate < 1) pollingRate = 1;
  VF("MSG: System, start input sense service task (rate "); V(pollingRate); VF("ms priority 7)... ");
  if (tasks.add(pollingRate, 0, true, 7, sensesPoll, "SysSens")) { VLF("success"); } else { VLF("FAILED!"); }

  // start telescope object
  telescope.init(FirmwareName, FirmwareVersionMajor, FirmwareVersionMinor, FirmwareVersionPatch, FirmwareVersionConfig);

  // start command channel tasks
  commandChannelInit();

  tasks.yield(2000);

  // start any plugins
  #if PLUGIN1 != OFF
    PLUGIN1.init();
  #endif
  #if PLUGIN2 != OFF
    PLUGIN2.init();
  #endif
  #if PLUGIN3 != OFF
    PLUGIN3.init();
  #endif
  #if PLUGIN4 != OFF
    PLUGIN4.init();
  #endif
  #if PLUGIN5 != OFF
    PLUGIN5.init();
  #endif
  #if PLUGIN6 != OFF
    PLUGIN6.init();
  #endif
  #if PLUGIN7 != OFF
    PLUGIN7.init();
  #endif
  #if PLUGIN8 != OFF
    PLUGIN8.init();
  #endif

  // start task manager debug events
  #if DEBUG == PROFILER
    tasks.add(142, 0, true, 7, profiler, "Profilr");
  #endif

  sense.poll();

  telescope.ready = true;
}

void loop() {
  tasks.yield();
}

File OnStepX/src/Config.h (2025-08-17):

/* ---------------------------------------------------------------------------------------------------------------------------------
 * Configuration for OnStepX
 *
 *          For more information on setting OnStep up see http://www.stellarjourney.com/index.php?r=site/equipment_onstep 
 *                      and join the OnStep Groups.io at https://groups.io/g/onstep
 * 
 *           *** Read the compiler warnings and errors, they are there to help guard against invalid configurations ***
 *
 * ---------------------------------------------------------------------------------------------------------------------------------
 * ADJUST THE FOLLOWING TO CONFIGURE YOUR CONTROLLER FEATURES ----------------------------------------------------------------------
 * <-Req'd = always must set, <-Often = usually must set, Option = optional, Adjust = adjust as req'd, Infreq = infrequently changed
*/
//      Parameter Name              Value   Default  Notes                                                                      Hint

// =================================================================================================================================
// CONTROLLER ======================================================================================================================
#define HOST_NAME                "OnStepX" // nStep", Hostname for this device up to 16 chars.                                 Adjust
// PINMAP ------------------------------------------------- see https://onstep.groups.io/g/main/wiki/Configuration_Controller#PINMAP
#define PINMAP                        Juwei17max //    OFF, Choose from: MiniPCB, MiniPCB2, MaxPCB2, MaxESP3, CNC3, STM32Blue,      <-Req'd
                                          //         MaxSTM3, FYSETC_S6_2, etc.  Other boards and more info. in ~/src/Constants.h
// SERIAL PORT COMMAND CHANNELS --------------------- see https://onstep.groups.io/g/main/wiki/Configuration_Controller#SERIAL_PORTS
#define SERIAL_A_BAUD_DEFAULT        9600 //   9600, n. Where n=9600,19200,57600,115200,230400,460800 (common baud rates.)    Infreq
#define SERIAL_B_BAUD_DEFAULT        115200 //   9600, n. Baud rate as above. See (src/pinmaps/) for Serial port assignments.   Infreq
#define SERIAL_B_ESP_FLASHING         ON //ON //    OFF, ON Upload ESP8266 WiFi firmware through SERIAL_B with :ESPFLASH# cmd.    Option
#define SERIAL_C_BAUD_DEFAULT         OFF //    OFF, n. Baud rate as above. See (src/pinmaps/) for Serial port assignments.   Infreq
#define SERIAL_D_BAUD_DEFAULT         OFF //    OFF, n. Baud rate as above. See (src/pinmaps/) for Serial port assignments.   Infreq
#define SERIAL_E_BAUD_DEFAULT         OFF //    OFF, n. Baud rate as above. See (src/pinmaps/) for Serial port assignments.   Infreq
#define SERIAL_RADIO                  OFF //    OFF, Use BLUETOOTH or WIFI_ACCESS_POINT or WIFI_STATION (ESP32 only.)         Option
#define SERIAL_GPS_BAUD             38400
// STATUS --------------------------------------------- see https://onstep.groups.io/g/main/wiki/Configuration_Controller#STATUS_LED
#define STATUS_LED                    ON //    OFF, Steady illumination if no error, blinks w/error code otherwise.          Option

// RETICLE CONTROL ------------------------------- see https://onstep.groups.io/g/main/wiki/Configuration_Controller#RETICLE_CONTROL
#define RETICLE_LED_DEFAULT           OFF //    OFF, n. Where n=0..255 (0..100%) activates feature sets default brightness.   Option
#define RETICLE_LED_MEMORY            OFF //    OFF, ON Remember reticle brightness across power cycles.                      Option
#define RETICLE_LED_INVERT            OFF //    OFF, ON Inverts control for cases where 0V is max brightness.                 Option

// WEATHER SENSOR --------------------------------- see https://onstep.groups.io/g/main/wiki/Configuration_Controller#WEATHER_SENSOR
#define WEATHER                       BME280_0x76 //    OFF, BME280 (I2C 0x77,) BME280_0x76, BME280_SPI (see pinmap for CS.)          Option
                                          //         BMP280 (I2C 0x77,) BMP280_0x76, BMP280_SPI (see pinmap for CS.)
                                          //         BME280 or BMP280 for temperature, pressure.  BME280 for humidity also.

// SIGNALING ------------------------------------------- see https://onstep.groups.io/g/main/wiki/Configuration_Controller#SIGNALING
#define STEP_WAVE_FORM             SQUARE // SQUARE, PULSE Step signal wave form faster rates. SQUARE best signal integrity.  Adjust
                                          //         Applies to all axes.

// NON-VOLATILE MEMORY ---------------------------------------- see https://onstep.groups.io/g/main/wiki/Configuration_Controller#NV
#define NV_DRIVER              NV_2464 // NV_DEF, Use platforms default non-volatile device to remember runtime settings.  Option
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

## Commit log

2025-08-10 HW, onstepx
    [ME3116.kicad_sch, OnStep_ESPMAX3.kicad_sch, OnStep_MaxESP4.kicad_sch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]
2025-08-14 pictures, stls
    [GPS_holder.stl, PCB_front_RJsmall.stl, back_cover_DS1820_inside.stl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]
2025-08-17 added homing ring stl
    [homing_ring.stl, knob.stp]

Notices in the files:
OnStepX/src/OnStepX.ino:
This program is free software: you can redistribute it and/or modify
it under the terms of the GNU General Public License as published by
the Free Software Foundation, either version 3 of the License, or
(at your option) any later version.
